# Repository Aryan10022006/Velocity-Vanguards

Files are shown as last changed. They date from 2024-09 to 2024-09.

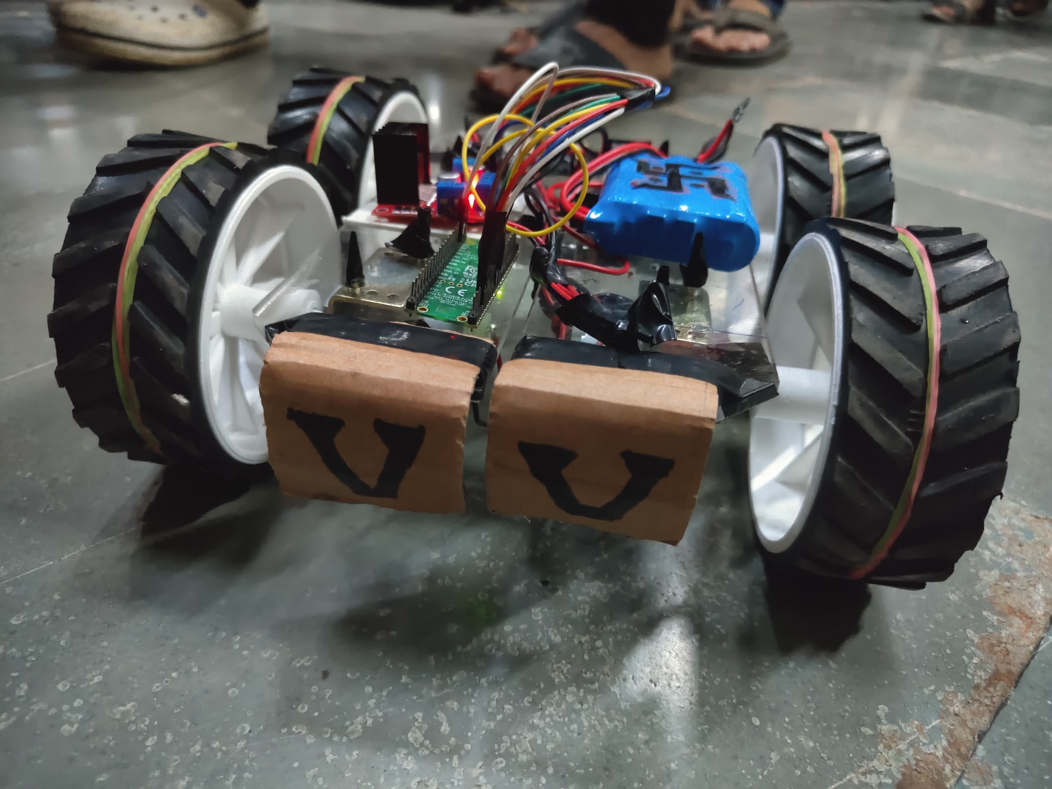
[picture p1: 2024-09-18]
Electrical_Design/WhatsApp Image 2024-09-07 at 18.34.08_59a5776c.jpg

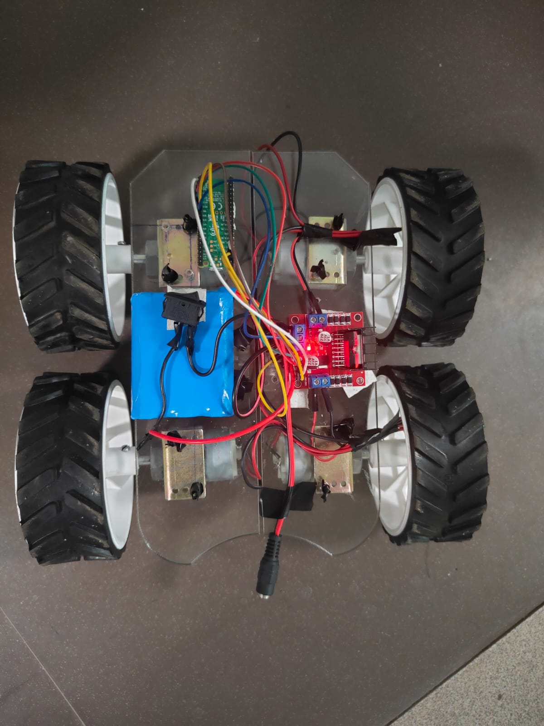
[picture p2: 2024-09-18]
Electrical_Design/WhatsApp Image 2024-09-10 at 19.03.17_d3433f75.jpg

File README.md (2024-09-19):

# Velocity-Vanguards

**Bot Name: Vector**

**1. Photos:** Check Team_Gallery for the crazy pics of our XLR8 journey! 

**2. What Makes Our Bot Different from the Rest**

While many teams utilized similar sensors like the MPU6050 gyroscope, ultrasonic sensors, and servo motors, our bot stood out due to the following features:

a. Two-Part Chassis Design: We split the chassis into two parts—left and right—which improved stability and torque distribution. This design allowed the bot to traverse uneven terrain and cross obstacles more effectively. Unlike other bots that struggled on challenging surfaces, ours could maintain control on inclines and rough tracks.

b. 360-Degree Obstacle Detection Without Servo Motor: While most teams used a servo motor to rotate the ultrasonic sensor for autonomous navigation, we took a different approach. We programmed our bot to rotate itself to scan the environment, providing 360-degree coverage. This eliminated the need for an additional servo motor, simplifying the design and reducing potential points of failure, all while maintaining accurate obstacle detection.

**3. Motivation for Our Idea and XLR8 Journey**

The idea for our bot was born from the need for a robust solution that could effectively navigate unpredictable terrain while maintaining stability and control. Traditional robots tend to struggle with balance when encountering uneven surfaces, leading to inefficiencies and potential breakdowns. We realized that a rigid, single-body chassis was a limitation in such environments. Our goal was to design a bot that could dynamically adjust to the terrain, making it more versatile in real-world scenarios.

By incorporating a split chassis with a hinge in the center, we allowed each half of the bot to move independently. This provided superior adaptability on rough terrains, allowing one side of the bot to react to obstacles differently than the other, improving both balance and control. Through our journey in the XLR8 competition, we iterated on this design, refining the hinge mechanism to ensure it functioned smoothly under different loads and conditions. The process also helped us dive deeper into integrating sensors for more accurate obstacle detection and response.

We participated in XLR8 because we were genuinely enthusiastic about exploring the electrical aspects of the program. Electrical systems and circuitry are among our favorite topics, and the opportunity to dive deeper into these areas was incredibly exciting. Our involvement in XLR8 allowed us to immerse ourselves in hands-on experiences, expanding our knowledge and skills in a field we’re passionate about. This engagement not only enhanced our technical expertise but also fueled our curiosity and love for learning about the intricacies of electrical engineering an robotics.
We also attempted two electrical problem statements of AUV and MRT TEam which required quite brainstorming but after successful run for the both, our satisfaction was on another level.

**4. Resources Used**

    Hardware:

    1. Raspberry Pi Pico W for processing and wireless control
    2. MPU6050 Gyroscope for motion tracking and orientation
    3. Ultrasonic Sensor for obstacle detection and navigation
    4. L298N Motor Driver for controlling the motors
    5. 100 RPM Motors to drive the wheels
    6. RGB LEDs to signal movement direction (based on AUV challenge)
    7. Two-Part Modular Acrylic Chassis for better stability and obstacle-crossing capabilities
    8. Li-ion Battery Pack (7.4V) to power the entire system
    
    Software:

    1. Arduino IDE for coding the Raspberry Pi Pico W
    2. Pre-installed libraries:
        WiFi.h for wireless communication
        Wire.h for I2C communication with the MPU6050
        ESP8266WiFi.h for connecting ESP01 if necessary
        math.h for motion and direction calculations
    
    Online Resources and Guides:

    1. Raspberry Pi Pico W official documentation
    2. Tutorials on MPU6050 and ultrasonic sensor integration
    3. Support and mentorship from the ERC Club, IIT Bombay
    4. Our XLR8 Mentor: Animesh Jain

**5. Mechanical Design:**

The CAD file has been attached here with name XLR8_Velocity-Vanguards.dxf
The chassis was designed with two distinct sections:

Left and Right parts, each holding its own motor and electronics, connected at the center.
This modular approach ensures:
1. Improved load distribution for better balance and handling.
2. Enhanced stability during turns and when navigating inclines or rough surfaces.
3. The bot’s ability to cross obstacles more easily by flexing its chassis.
4. This design has the added advantage of offering better control and responsiveness while reducing mechanical complexity (as no servo motor is required for sensor rotation).

**6. Electrical Design (Circuit Diagram):**

The electrical design includes:

1. Raspberry Pi Pico W acting as the controller and wireless communication hub.
2. MPU6050 Gyroscope positioned centrally for accurate tilt and orientation tracking.
3. Ultrasonic sensor mounted in the front for obstacle detection, enabling 360-degree navigation by rotating the bot instead of using a servo motor. (for MRT Problem Statement)
4. L298N Motor Driver connected to two 100 RPM motors on each side, each driving one side of the two-part chassis.
5. RGB LEDs connected to signal the bot's direction (as per the AUV challenge).
6. Li-ion battery pack powering the entire system with regulated voltage and grounding.

The circuit diagram can be found in the folder named 'Electrical_Design' in this repository
    
**7. Code for the RPi Pico W**

Our code handles:

1. IMU (gyroscope) data processing to track orientation and adjust motor speeds accordingly.
2. Obstacle detection using the ultrasonic sensor: The bot rotates itself to scan for obstacles, offering 360-degree coverage without requiring a servo motor. 
3. Motor control: Based on the sensor inputs, the bot adjusts its movement speed and direction to navigate autonomously. For this model two levels of speed were set.
4. RGB LED feedback: RGB LEDs light up in different colors to indicate the direction of movement (forward, reverse, left, right).
5. Wireless control via the Raspberry Pi Pico W for real-time commands and feedback with delay time of 100 ms

The Code files for Autonomous Navigation and for XLR8 Run with RGB light can be found in the Code Folder in this Repository

**8. Help Received from Mentors**

Our mentors from the ERC Club, IIT Bombay, played a key role in helping us overcome several technical challenges. They provided guidance on:
Circuit design: Ensuring efficient power management to keep the bot running longer on battery power.
Debugging our problems late nights
Answering our silly quesitons
Perfecting us in Soldering
Their assistance helped us fine-tune the bot for both autonomous navigation and manual control, making it highly versatile.

Our XLR8 Mentor Animesh Jain helped us in various factors:

As soon as the codified session was done he suggested us to get laser cutting of the chassis to avoid unnecessary rush, he himself accompanied us for laser cutting and explained how the machine work and what all precaution that we need to take
He supported us on the idea of two part design and told about necessary consideration that we must take
Once after completion, when our bot was toppling we changed the design and lowered the COM
His motivation to wind up earlier and look forward to solve problem statement for getting into the Tech Teams kept us going thorugh the entire XLR8 Journey
His tips and guidelines on how to control our bot on each and every obstacle, when to slow down or when to spped up were remarkable

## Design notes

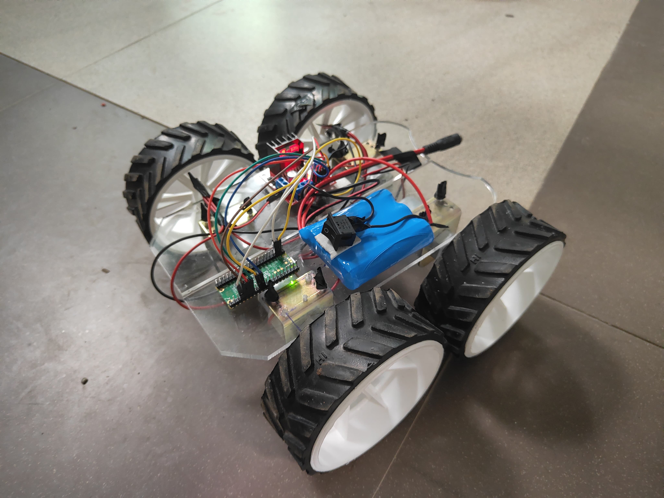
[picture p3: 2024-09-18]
Electrical_Design/WhatsApp Image 2024-09-07 at 00.42.31_089a854b.jpg

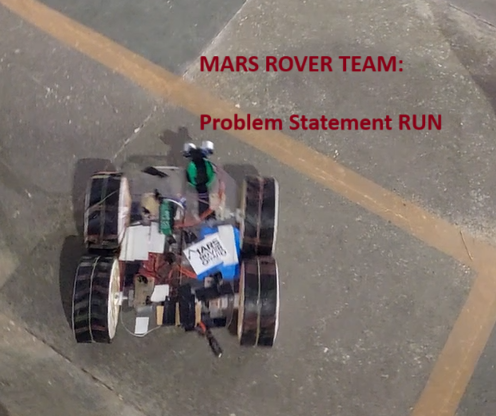
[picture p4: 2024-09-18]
Team_Gallery/mars_rover_team_run.png

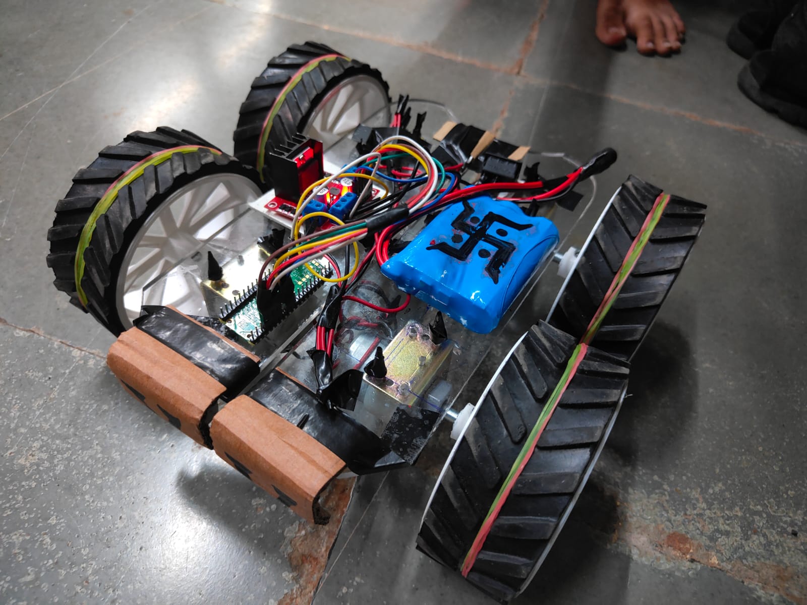
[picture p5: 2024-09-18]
Team_Gallery/WhatsApp Image 2024-09-07 at 18.33.28_d74fad8b.jpg

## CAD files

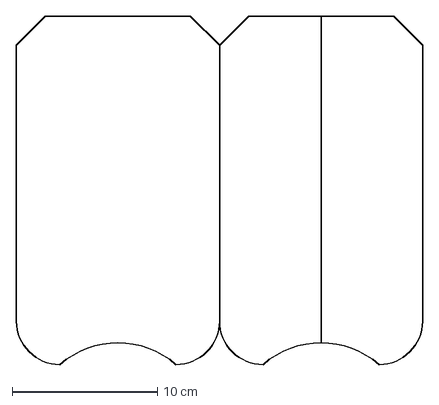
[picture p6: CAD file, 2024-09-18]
XLR8_Velocity-Vanguards.dxf
28.0 x 24.0 cm

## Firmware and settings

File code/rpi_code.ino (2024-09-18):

#include <WiFi.h>
#include <typeinfo>
#include <string.h>
#include <stdio.h>

// SSID and password for the access point
const char* ssid = "VVS2028"; //Enter your team name as the SSID here
const char* password = "vanguards"; // Make a good password!

// Define a structure to hold IMU (Inertial Measurement Unit) data
typedef struct {
  float gx, gy, gz;
} IMUData;

IMUData myMessage; // Create a variable to store received IMU data
int cmd = 0;       // Initialize motor control command variable
int spd = 0;       // Initialize motor speed variable

// Function to update motor control based on received IMU data
void updateMotorControl() {
  float gx = myMessage.gx;
  float gy = myMessage.gy;
  float gz = myMessage.gz;

  // Motor control logic based on IMU data
  if ((gz != 0) && (gx != 0) && (abs(gy) < 2)) {
    spd = constrain(abs(map((atan2(gx, gz) * 180 / PI), 0, 90, 0, 255)), 0, 255);
    cmd = (gx > 0) ? 1 : 2; // Forward or backward
  } else if ((gz != 0) && (gy != 0) && (abs(gx) < 2)) {
    spd = constrain(abs(map((atan2(gy, gz) * 180 / PI), 0, 90, 0, 255)), 0, 255);
    cmd = (gy > 0) ? 3 : 4; // Right or left
  } else {
    cmd = 0; // Stop
    spd = 0;
  }

  // Adjust motor speed thresholds
  if (spd > 60 && spd < 150) {
    spd = 150;
  }
  if (spd > 150 && spd < 255) {
    spd = 255;
  }

  // Display motor control information
  Serial.print("cmd: ");
  Serial.print(cmd);   // Display motor command
  Serial.print(", speed: ");
  Serial.println(spd); // Display motor speed
}

// Pin assignments for motor control
const int ENA = 8;
const int ENB = 9;

const int IN1 = 10;
const int IN2 = 11;
const int IN3 = 12;
const int IN4 = 13;
const int RE = 3;
const int BL = 4;
const int GR = 5;
const int HI = 2;
// Create a WiFiServer object for the TCP server
WiFiServer server(80);

void setup() {
  // Start Serial for debugging
  Serial.begin(115200);
    // Configure motor control pins as outputs
  pinMode(LED_BUILTIN, OUTPUT);
  pinMode(ENA, OUTPUT);
  pinMode(IN1, OUTPUT);
  pinMode(IN2, OUTPUT);
  pinMode(ENB, OUTPUT);
  pinMode(IN3, OUTPUT);
  pinMode(IN4, OUTPUT);
  pinMode(RE, OUTPUT);
  pinMode(GR, OUTPUT);
  pinMode(BL, OUTPUT);
  pinMode(HI, OUTPUT);

  // Set up the access point
  Serial.println("Setting up WiFi AP...");
  WiFi.softAP(ssid, password);
  
  IPAddress IP = WiFi.softAPIP();
  Serial.print("AP IP address: ");
  Serial.println(IP);
  
  // Start the server
  server.begin();

  WiFiClient client = server.available();
  if (client) {
    Serial.println("Client is connected");
  }

}

void applyMotorControl() {
  switch (cmd) {
    case 1:  // Forward
      digitalWrite(IN1,HIGH); //(INCOMPLETE)
      digitalWrite(IN2,LOW); //(INCOMPLETE)
      digitalWrite(IN3,HIGH); //(INCOMPLETE)
      digitalWrite(IN4,LOW); //(INCOMPLETE)
      analogWrite(RE,255);
      analogWrite(HI,250);
      analogWrite(GR,255);
      analogWrite(BL,120);
      break;
    case 2:  // Backward
      digitalWrite(IN1,LOW); //(INCOMPLETE)
      digitalWrite(IN2,HIGH); //(INCOMPLETE)
      digitalWrite(IN3,LOW); //(INCOMPLETE)
      digitalWrite(IN4,HIGH); //(INCOMPLETE)
      digitalWrite(RE,HIGH);
      digitalWrite(HI,LOW);
      digitalWrite(GR, LOW);
      digitalWrite(BL,LOW);
      

      break;
    case 3:  // Right
      digitalWrite(IN1,LOW); //(INCOMPLETE)
      digitalWrite(IN2,HIGH); //(INCOMPLETE)
      digitalWrite(IN3,HIGH); //(INCOMPLETE)
      digitalWrite(IN4,LOW); //(INCOMPLETE)
      analogWrite(RE,180);
      analogWrite(HI,250);
      analogWrite(GR,255);
      analogWrite(BL,120);
    
      break;
    case 4:  // Left
      digitalWrite(IN1,HIGH); //(INCOMPLETE)
      digitalWrite(IN2,LOW); //(INCOMPLETE)
      digitalWrite(IN3,LOW); //(INCOMPLETE)
      digitalWrite(IN4,HIGH); //(INCOMPLETE)
      analogWrite(RE,255);
      analogWrite(HI,250);
      analogWrite(GR,120);
      analogWrite(BL,255);
      break;
    default:  // Stop
      digitalWrite(IN1,LOW); //(INCOMPLETE)
      digitalWrite(IN2,LOW); //(INCOMPLETE)
      digitalWrite(IN3,LOW); //(INCOMPLETE)
      digitalWrite(IN4,LOW); //(INCOMPLETE)
      digitalWrite(RE,HIGH);
      digitalWrite(BL,HIGH);
      digitalWrite(GR,HIGH);
      digitalWrite(HI,LOW);
     

      spd = 0;
      break; 
  }

  // Apply the calculated motor speed to both motors
  analogWrite(ENA, spd);
  analogWrite(ENB, spd);
}

void loop() {
 
  
  // Check if a client has connected
  WiFiClient client = server.available();
  //if (client) {
    //while (client.connected()) {
      if (client.available()) {
        digitalWrite(LED_BUILTIN, HIGH);
        String request = client.readStringUntil('\r');
        Serial.print("Received data: ");
        //Serial.println(request);
        char chararr[50];
        request.toCharArray(chararr, sizeof(chararr));

        Serial.println(chararr);
        char *res;
        float arr[3];
        int i = 0;

        res = strtok(chararr , " ");
        while(res != NULL){
          Serial.println(res);
          String strr = String(res);
          float val = strr.toFloat();
          Serial.println(val);
          res = strtok(NULL, " ");
          arr[i]= val;
          i++;
        }
        myMessage.gx = arr[0];
        myMessage.gy = arr[1];
        myMessage.gz = arr[2];
        updateMotorControl();
        applyMotorControl();
        digitalWrite(LED_BUILTIN, LOW);}
      digitalWrite(LED_BUILTIN, LOW);
   // Continuously update and apply motor control
  delay(100);}// Delay to control loop speed

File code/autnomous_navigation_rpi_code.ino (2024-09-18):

#include <Arduino.h>

// Define motor control pins
const int ENA = 8;
const int ENB = 9;
const int IN1 = 10;
const int IN2 = 11;
const int IN3 = 12;
const int IN4 = 13;

// Ultrasonic sensor pins
const int TRIG_PIN = 15;  // Trigger pin for ultrasonic sensor
const int ECHO_PIN = 14;  // Echo pin for ultrasonic sensor

// Constants
const long minDistance = 20;        // Minimum distance to obstacle before stopping (cm)
const long checkInterval = 100;     // Time interval for checking distance (ms)
const int maxSpeed = 255;           // Maximum motor speed

// Function prototypes
long measureDistance();
void moveForward(int speed);
void moveBackward(int speed);
void stopMotors();
void turnLeft(int angle);
void turnRight(int angle);

// Setup function
void setup() {
  Serial.begin(115200);

  // Initialize motor pins as outputs
  pinMode(ENA, OUTPUT);
  pinMode(ENB, OUTPUT);
  pinMode(IN1, OUTPUT);
  pinMode(IN2, OUTPUT);
  pinMode(IN3, OUTPUT);
  pinMode(IN4, OUTPUT);

  // Initialize ultrasonic sensor pins
  pinMode(TRIG_PIN, OUTPUT);
  pinMode(ECHO_PIN, INPUT);

  // Start by stopping the motors
  stopMotors();
}

// Main loop
void loop() {
  // Continuously move forward and check the distance every checkInterval ms
  unsigned long previousMillis = 0;

  while (true) {
    unsigned long currentMillis = millis();

    // If it's time to check the distance
    if (currentMillis - previousMillis >= checkInterval) {
      previousMillis = currentMillis;

      // Measure the distance in front of the bot
      long frontDistance = measureDistance();
      Serial.print("Front Distance: ");
      Serial.println(frontDistance);

      // If an obstacle is detected within the minimum distance, stop and avoid
      if (frontDistance < minDistance) {
        stopMotors();
        delay(100);  // Short pause before deciding

        // Check all directions
        turnRight(45);
        long right45Distance = measureDistance();
        Serial.print("45 Right Distance: ");
        Serial.println(right45Distance);

        turnLeft(90);  // Move back to center and turn left 45
        long left45Distance = measureDistance();
        Serial.print("45 Left Distance: ");
        Serial.println(left45Distance);

        turnRight(45);  // Back to the center (forward position)

        turnRight(90);  // Check 90-degree right
        long right90Distance = measureDistance();
        Serial.print("90 Right Distance: ");
        Serial.println(right90Distance);

        turnLeft(180);  // Check 90-degree left
        long left90Distance = measureDistance();
        Serial.print("90 Left Distance: ");
        Serial.println(left90Distance);

        turnRight(90);  // Return to forward position

        // Decide the best direction to move based on the measurements
        if (right90Distance > frontDistance && right90Distance > left90Distance) {
          turnRight(90);  // Turn 90 degrees right if the path is clear
        } else if (left90Distance > frontDistance && left90Distance > right90Distance) {
          turnLeft(90);  // Turn 90 degrees left if the path is clear
        } else if (right45Distance > frontDistance) {
          turnRight(45);  // Turn 45 degrees right
        } else if (left45Distance > frontDistance) {
          turnLeft(45);  // Turn 45 degrees left
        } else {
          moveBackward(maxSpeed);  // If no clear direction, move backward and try again
          delay(500);
          stopMotors();
        }
      } else {
        // If the path is clear, continue moving forward
        moveForward(maxSpeed);
      }
    }
  }
}

// Function to measure distance using ultrasonic sensor
long measureDistance() {
  digitalWrite(TRIG_PIN, LOW);
  delayMicroseconds(2);
  digitalWrite(TRIG_PIN, HIGH);
  delayMicroseconds(10);
  digitalWrite(TRIG_PIN, LOW);

  long duration = pulseIn(ECHO_PIN, HIGH);
  long distance = (duration * 0.0343) / 2;  // Convert time to distance in cm

  return distance;
}

// Function to move forward
void moveForward(int speed) {
  digitalWrite(IN1, HIGH);
  digitalWrite(IN2, LOW);
  digitalWrite(IN3, HIGH);
  digitalWrite(IN4, LOW);
  analogWrite(ENA, speed);
  analogWrite(ENB, speed);
}

// Function to move backward
void moveBackward(int speed) {
  digitalWrite(IN1, LOW);
  digitalWrite(IN2, HIGH);
  digitalWrite(IN3, LOW);
  digitalWrite(IN4, HIGH);
  analogWrite(ENA, speed);
  analogWrite(ENB, speed);
}

// Function to stop the motors
void stopMotors() {
  digitalWrite(IN1, LOW);
  digitalWrite(IN2, LOW);
  digitalWrite(IN3, LOW);
  digitalWrite(IN4, LOW);
  analogWrite(ENA, 0);
  analogWrite(ENB, 0);
}

// Function to turn left by a specific angle (e.g., 45 or 90 degrees)
void turnLeft(int angle) {
  int turnTime = (angle == 45) ? 400 : 800;  // Adjust values based on testing
  digitalWrite(IN1, LOW);
  digitalWrite(IN2, HIGH);
  digitalWrite(IN3, HIGH);
  digitalWrite(IN4, LOW);
  analogWrite(ENA, 255);
  analogWrite(ENB, 255);
  delay(turnTime);
  stopMotors();
}

// Function to turn right by a specific angle (e.g., 45 or 90 degrees)
void turnRight(int angle) {
  int turnTime = (angle == 45) ? 400 : 800;  // Adjust values based on testing
  digitalWrite(IN1, HIGH);
  digitalWrite(IN2, LOW);
  digitalWrite(IN3, LOW);
  digitalWrite(IN4, HIGH);
  analogWrite(ENA, 255);
  analogWrite(ENB, 255);
  delay(turnTime);
  stopMotors();
}
